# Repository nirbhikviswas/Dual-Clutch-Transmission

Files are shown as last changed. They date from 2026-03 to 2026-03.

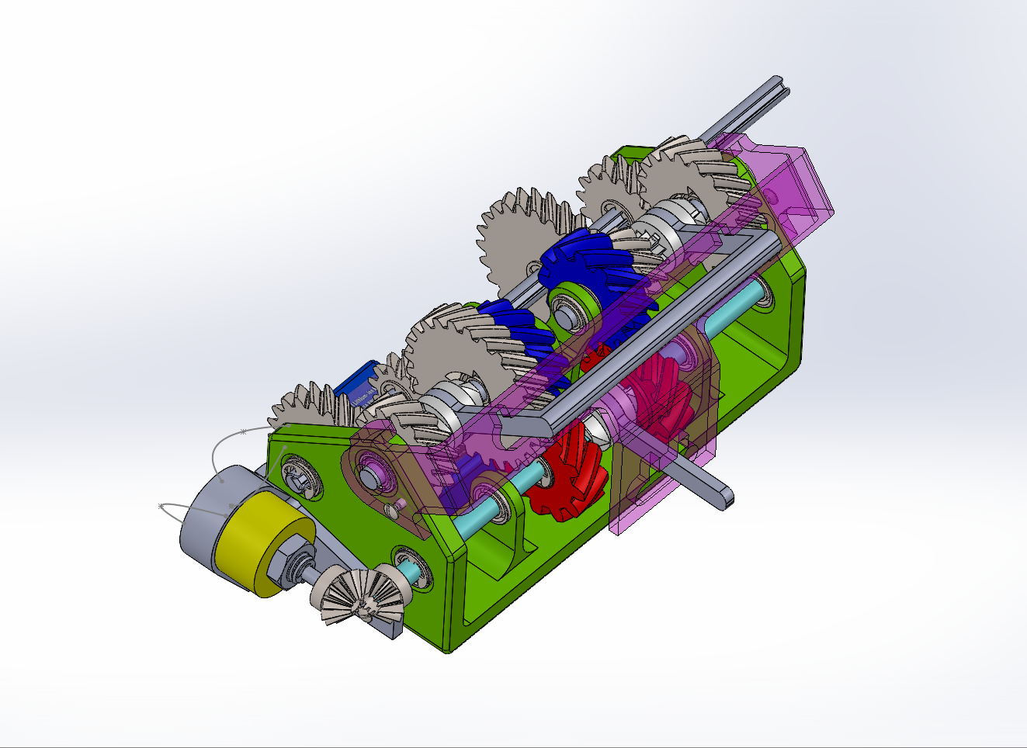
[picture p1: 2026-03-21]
Docs and Media/media/full assembly image 3.png

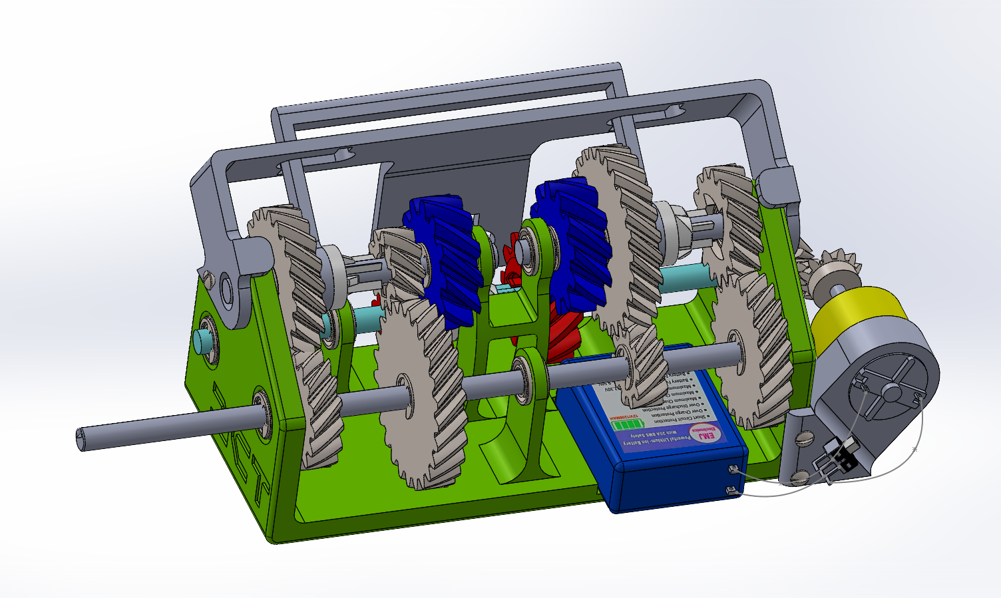
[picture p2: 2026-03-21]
Docs and Media/media/full assembly image 2.png

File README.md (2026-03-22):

# ⚙️ 4-Speed Modular Dual-Clutch Transmission (DCT)

 
> full assembly image 3
> 

## 📖 Description & Background
This repository contains the CAD files and assembly documentation for a **fully modular, 3D-printable 4-speed Dual-Clutch Transmission (DCT)**. It is powered by a 6V DC motor and designed to demonstrate high-efficiency kinetic energy transfer without the need for complex friction plates.

### 🚗 The Engineering: DCT vs. Manual Transmission
A traditional manual transmission interrupts power flow during a shift (the "neutral" gap). A Dual-Clutch Transmission solves this by splitting the gears across two independent shafts:
* **The Pros:** Near-seamless torque delivery, faster shift times, and higher mechanical efficiency since the "next" gear is pre-selected while the current one is driving.
* **The Cons:** Higher mechanical complexity, increased weight, and in real-world applications, complex thermal and fluid management. 

This model recreates that continuous power flow using a unique mechanical linkage, making the complex logic of a DCT visible and accessible.

---

## 🌟 Key Features & Innovations

### 1. The "Linked-Shift" Mechanical Logic
Real DCTs use electronic actuators (TCUs) to independently engage clutches. To make this model accessible and purely mechanical, we implemented a **slider-rod linkage system**. 
When you manually shift one set of gears, the connecting rod automatically pushes the slider on the opposite shaft into the "pre-selected" engagement position. This perfectly simulates the electronic hand-off of an actual DCT without needing a single line of code.

>

### 2. 100% Modular "Zero-Rigid-Fix" Design
The entire assembly follows a zero-rigid-fix philosophy:
* **No permanent adhesives:** Every gear, shaft, and bearing can be disassembled.
* **Tolerances:** Parts are engineered with optimized tolerances for 3D printing, ensuring a snug fit for bearings and minimized backlash between gear meshes. 

---

## 📐 Mechanical Architecture

### ⚙️ Gear Ratios Matrix
The transmission features four distinct speeds, alternating between the independent Odd and Even shafts:

| Gear | Ratio | Tooth Count (Drive:Driven) | Active Shaft |
| :--- | :--- | :--- | :--- |
| **1st** | 1:2.5 | 10T : 25T | Odd |
| **2nd** | 1:1.33 | 15T : 20T | Even |
| **3rd** | 1.33:1 | 20T : 15T | Odd |
| **4th** | 2.5:1 | 25T : 10T | Even |

### 🔩 Helical Gears vs. Spur Gears
To mimic high-performance automotive transmissions, this model utilizes **Helical Gears**.
* **Why Helical?** They offer smoother, progressive tooth engagement, operate much quieter than spur gears, and have a higher load-carrying capacity.
* **The Engineering Challenge:** Helical gears generate **axial thrust** (forces pushing the gear sideways along the shaft). 
* **Our Implementation:** We currently utilize circlips to lock the gears against this axial load as this small setup for demosntration of the mechanism has no load on the output shaft and the gears are small and 3D printed models. However, because circlips are not a solid, long-term solution for continuous thrust and loaded big useful models, upgrading to **shaft collars with thrust bearings** is recommended for higher loads.

### 🔺 Triangular Shaft Layout
Rather than a traditional straight-line sequential layout, this model uses a **Triangular Shaft Arrangement**. 
* **The Benefit:** It creates a much more compact gearbox. 
* **Load Distribution:** Torque is shared and distributed more evenly across the shafts. Bearings carry multi-directional loads, which reduces the bending moments on a single plane compared to a straight-line setup.

> 

---

## 📦 Bill of Materials (BOM)

All housing, gears, and shafts are fully 3D printable. The following hardware components are sourced from the market to complete the build:

| Item | Qty | Specification & Source Link | Use Case |
| :--- | :---: | :--- | :--- |
| **Miniature Ball Bearings** | 15 | [6800-ZZ (10x19x5mm)](https://omrook.com/6800-zz-id-10mm-od-19mm-h-5mm-miniature-ball-bearing/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) | Main shaft rotation |
| **DC Geared Motor** | 1 | [6V Arduino Geared Motor](https://www.amazon.in/INVENTO-1pcs-6V-Geared-Arduino/dp/B07R5FPR4D) *(or [Yellow Metal Variant](https://www.amazon.in/Geared-Motor-Original-Metal-Yellow/dp/B0B9KBJWW8))* | Main power drive |
| **E-Type Circlips** | 40 | [10mm Mild Steel (Black Coated)](https://onlyscrews.in/products/10mm-e-type-circlip-mild-steel-black-coated) | Internal gear locking |
| **External Circlips** | 10 | [10mm Shaft Diameter](https://omrook.com/external-circlip-for-10mm-shaft-diameter-100pcs/) | Shaft securing |
| **Thrust Bearings** | 10 | [AXK-1024 Needle Roller (10x24mm)](https://omrook.com/axk-1024-thrust-needle-roller-bearing-id-10mm-od-24mm/) | Axial load management |
| **Shaft Coupling** | 1 | [10mm x 6mm Aluminum Flexible](https://www.flyrobo.in/10mm-x-6mm-aluminum-flexible-shaft-coupling) | Motor-to-shaft connect |
| **Power Source** | 1 | [Lithium-ion Rechargeable Battery](https://www.amazon.in/Electronics-Lithium-ion-Rechargeable-Blutooth-Speakers/dp/B0G63YDBLR/) | Motor power |

*(Note: Standard M3/M4 machine screws are also required for mounting the motor and external housing).*

---

## 🛠️ Installation & Assembly Setup
1. **Print Tolerances:** Ensure your printer is well-calibrated. The gears require minimal stringing to prevent backlash.
2. **Post-Processing:** Sand the 3D-printed shafts lightly if the 6800-ZZ bearings do not slide on smoothly. **Do not force them**, as this breaks the zero-rigid-fix modularity.
3. **Linkage Alignment:** When installing the slider clutches, ensure the connecting rod is perfectly horizontal so shifting from 1st (Odd) smoothly engages 2nd (Even).

---

## 🚀 Roadmap & Future Upgrades
- [ ] **Thrust Upgrade:** Replace all load-bearing circlips with solid shaft collars to fully support the thrust bearings against the helical gear axial loads.
- [ ] **Electronic Actuation:** Design a mount for a servo motor to push the linkage rod, allowing for automated shifting via an Arduino.

## 🤝 Contributing
Suggestions and improvements are welcome! If you have ideas for better bearing mounts or modified gear ratios, please open an issue.

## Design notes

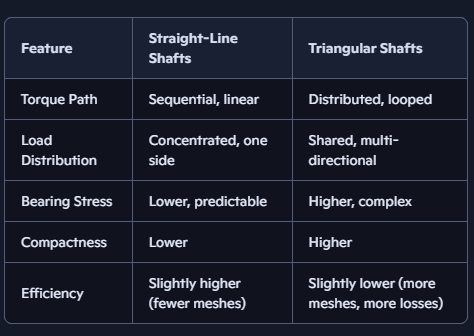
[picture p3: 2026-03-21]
Docs and Media/shaft arrangement pattern comparison 012347NV15February2026.png

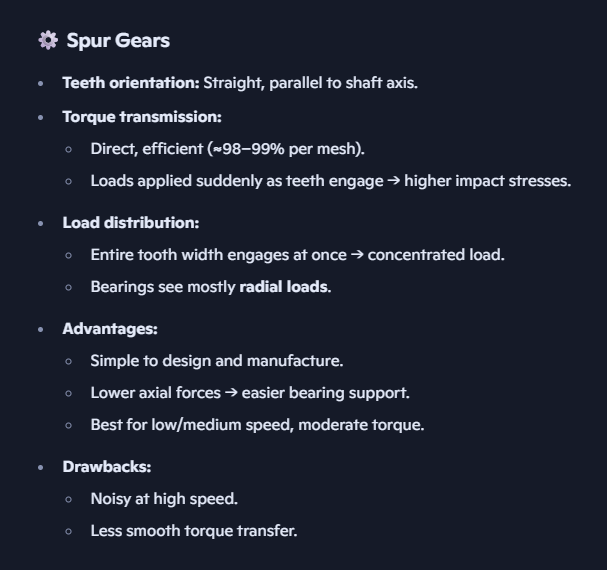
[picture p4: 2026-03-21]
Docs and Media/spur gears 012622NV15February2026.png

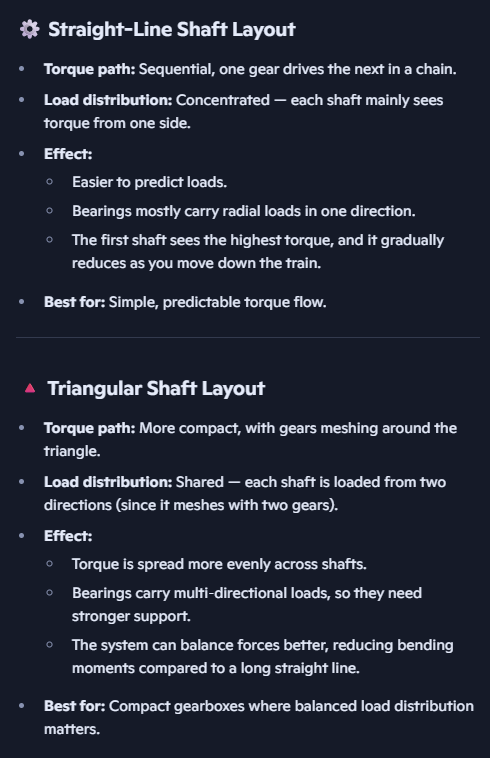
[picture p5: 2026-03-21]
Docs and Media/why triangular shaft arrangement 012313NV15February2026.png

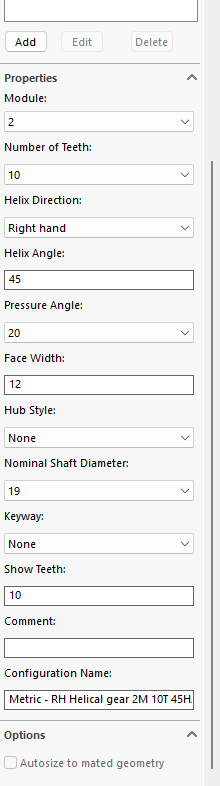
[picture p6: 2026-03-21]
Docs and Media/smallest gear 000956NV15February2026.png

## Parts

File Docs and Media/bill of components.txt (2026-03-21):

1. https://omrook.com/6800-zz-id-10mm-od-19mm-h-5mm-miniature-ball-bearing/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   X15

2. https://www.amazon.in/INVENTO-1pcs-6V-Geared-Arduino/dp/B07R5FPR4D
   OR https://www.amazon.in/Geared-Motor-Original-Metal-Yellow/dp/B0B9KBJWW8

3. https://onlyscrews.in/products/10mm-e-type-circlip-mild-steel-black-coated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 X40

4. https://omrook.com/external-circlip-for-10mm-shaft-diameter-100pcs/ X10

5. https://omrook.com/axk-1024-thrust-needle-roller-bearing-id-10mm-od-24mm/ X10

6. https://www.amazon.in/Electronics-Lithium-ion-Rechargeable-Blutooth-Speakers/dp/B0G63YDBLR/

7. https://www.flyrobo.in/10mm-x-6mm-aluminum-flexible-shaft-coupling

thrust bearings, screw, and some more things to be added

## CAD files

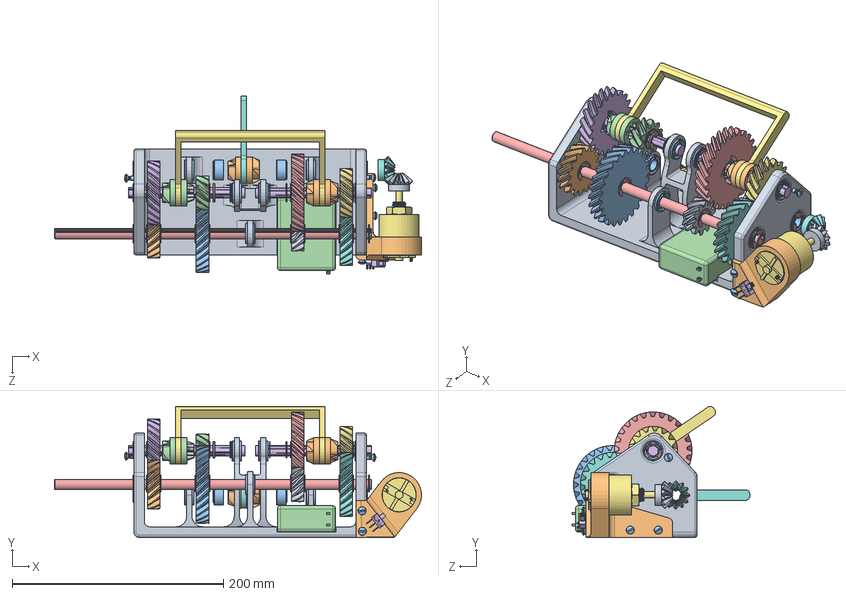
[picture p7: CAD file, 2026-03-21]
DCT CAD/FINAL ASSEMBLY.SLDASM
347.1 x 124.0 x 168.0 mm
Base
shifter gear1 x 2
radial ball bearing_68_am x 19
10T RH helical gear_indep
25T RH helical gear_3_am
20T RH helical gear_3_am
15T RH helical gear_3_am
20T LH helical gear_3_am
10T RH helical gear
15T LH helical gear_3_am
25T LH helical 44 deg not 45 gear_3_am
shifter gear2
output shaft
middle shaft with teeth x 2
motor_
straight bevel gear for shaft
straight bevel gear for motor1
motor hub ind
oval countersunk head tapping screw_am x 6
battery
e-ring external retaining ring_am x 25
slideswitch SS12D10_90_Degree
shifter handle
clutch shifter handle

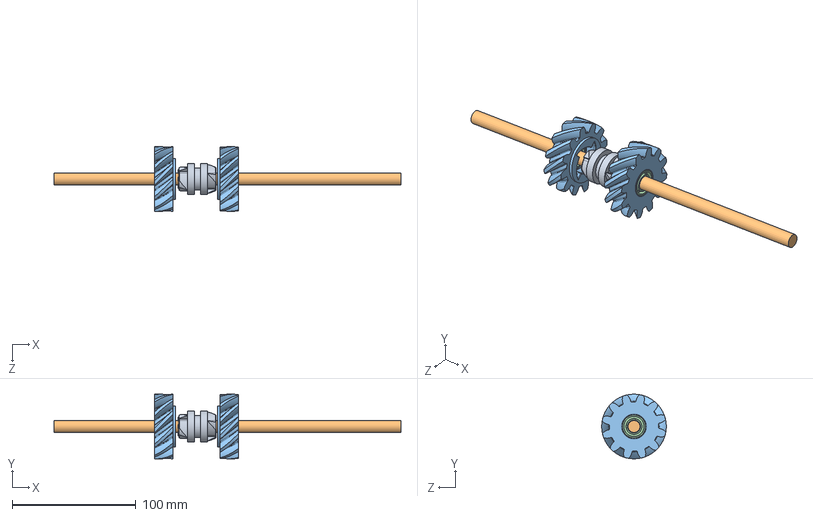
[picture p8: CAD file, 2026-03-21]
DCT CAD/reference assembly for creating feature.SLDASM
280.0 x 52.2 x 52.2 mm
input shaft
shifter gear1
helical gear_3_am 12 teeth x 2
radial ball bearing_68_am x 2

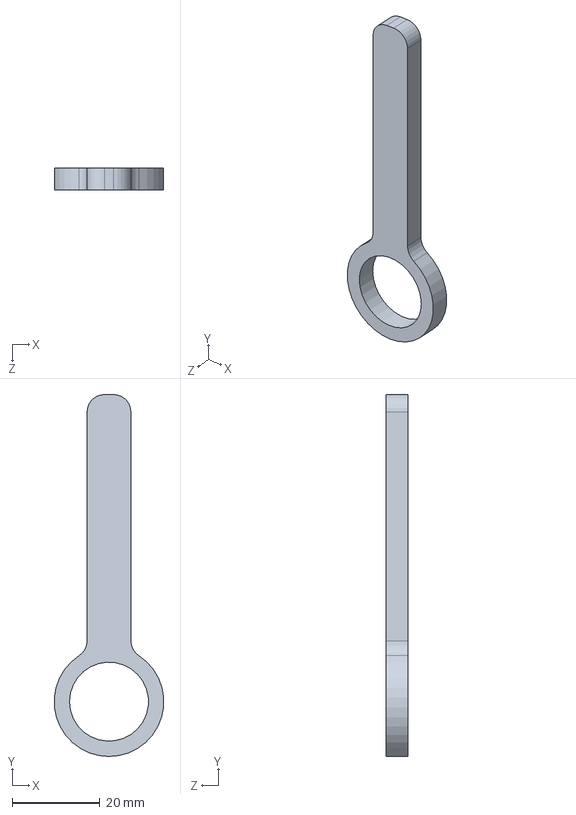
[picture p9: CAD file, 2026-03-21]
DCT CAD/clutch shifter handle.SLDPRT
24.9 x 82.5 x 5.00 mm

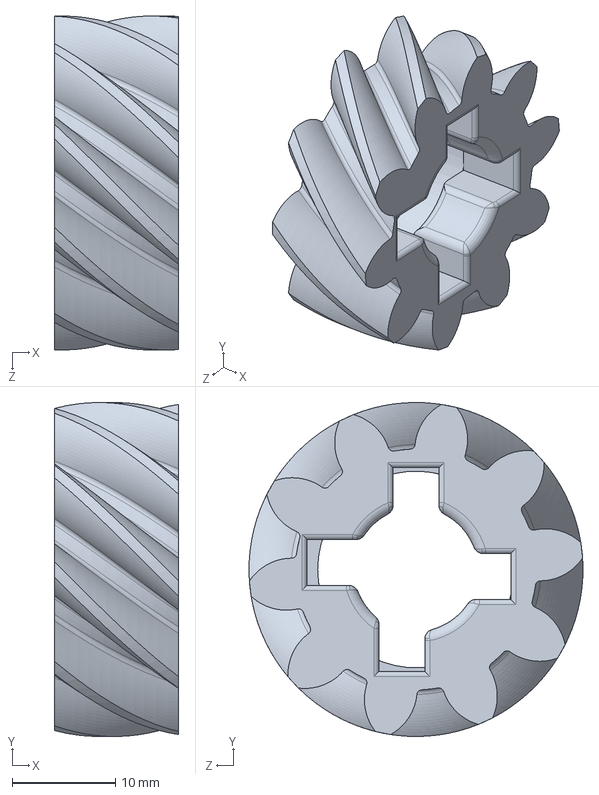
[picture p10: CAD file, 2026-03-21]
DCT CAD/10T RH helical gear_indep.SLDPRT
12.0 x 32.3 x 32.3 mm

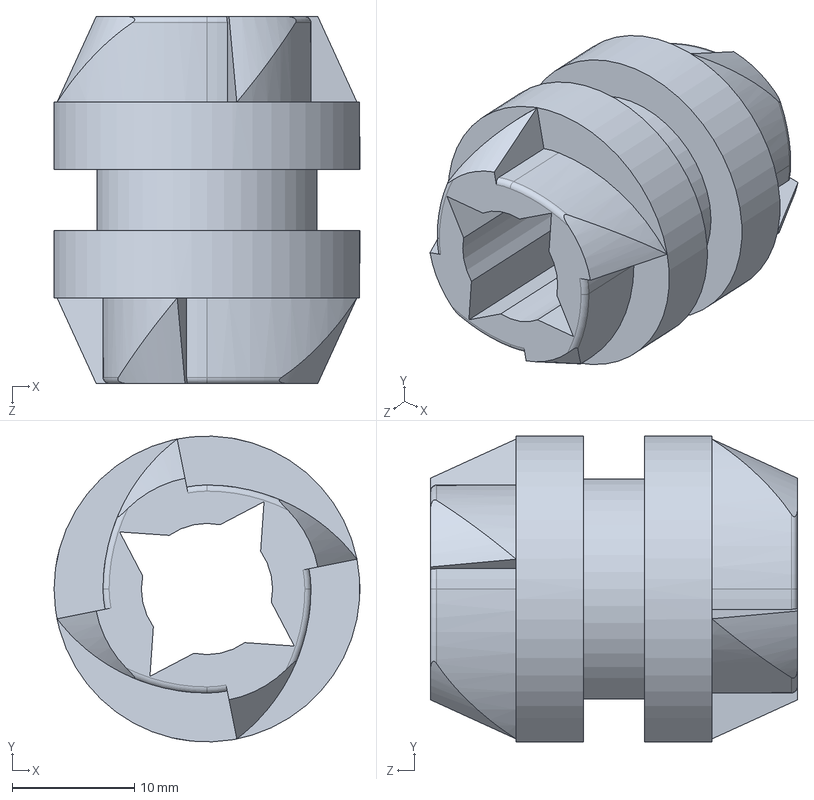
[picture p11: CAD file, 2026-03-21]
DCT CAD/shifter gear1.SLDPRT
25.0 x 25.0 x 30.0 mm

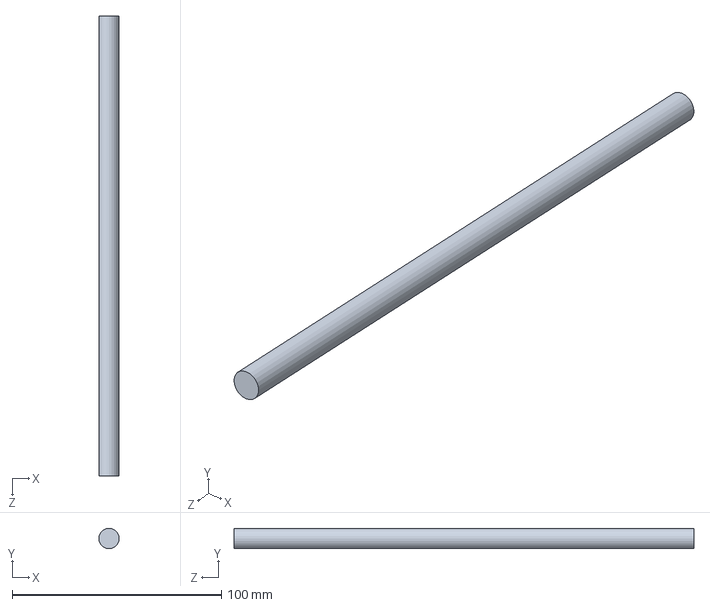
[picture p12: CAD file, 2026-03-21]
DCT CAD/middle shaft2.SLDPRT
9.72 x 9.72 x 220.0 mm

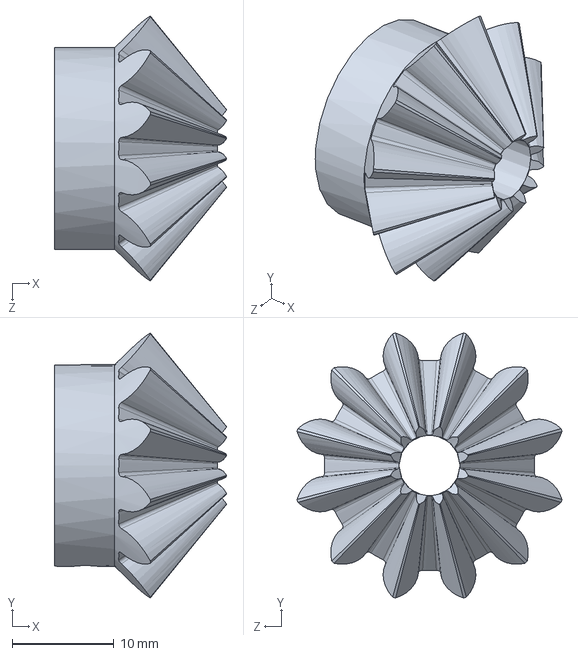
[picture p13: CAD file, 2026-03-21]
DCT CAD/straight bevel gear for motor.SLDPRT
16.9 x 26.0 x 26.0 mm

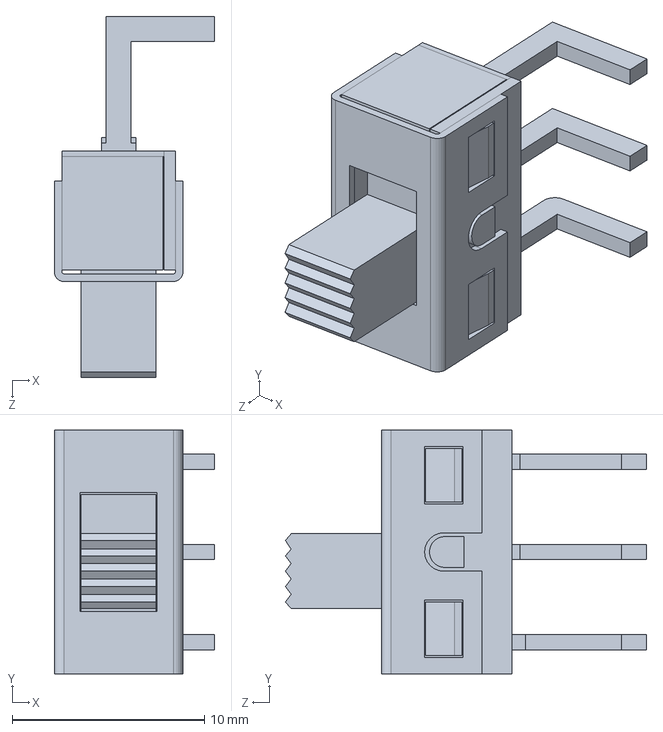
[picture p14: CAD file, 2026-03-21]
DCT CAD/slideswitch SS12D10_90_Degree.SLDPRT
8.35 x 12.7 x 18.8 mm

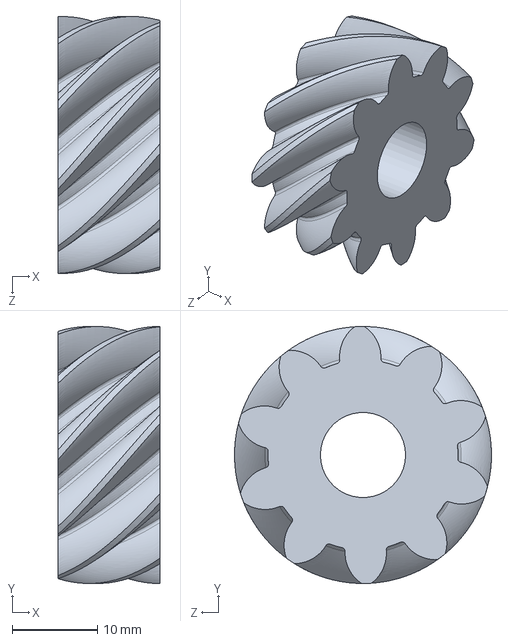
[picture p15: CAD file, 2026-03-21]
DCT CAD/10T LH helical 1.75 not 2 gear_3_am.SLDPRT
12.0 x 30.2 x 30.2 mm

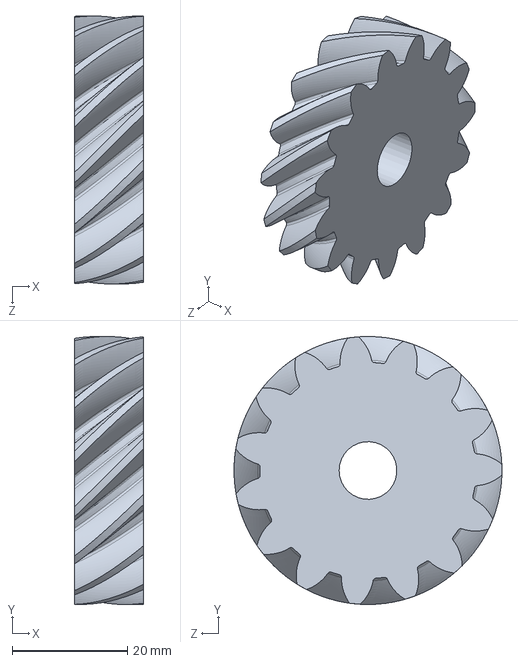
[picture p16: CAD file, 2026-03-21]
DCT CAD/25T LH helical 44 deg not 45 gear_3_am.SLDPRT
12.0 x 46.4 x 46.4 mm

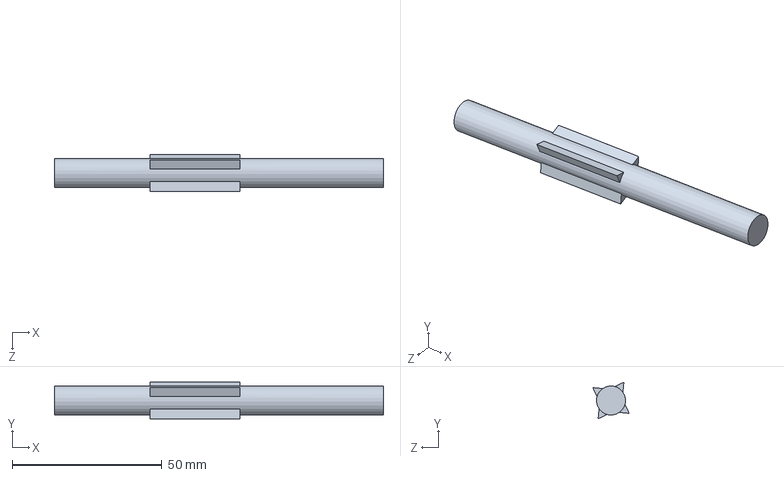
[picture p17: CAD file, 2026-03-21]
DCT CAD/middle shaft with teeth.SLDPRT
110.0 x 12.2 x 12.2 mm

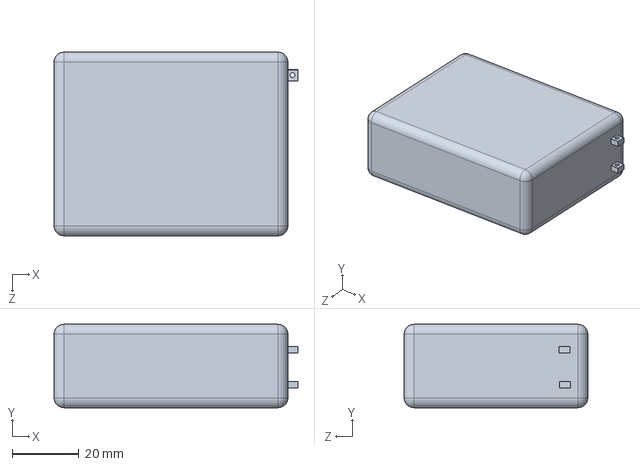
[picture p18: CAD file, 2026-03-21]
DCT CAD/battery.SLDPRT
73.0 x 25.0 x 55.0 mm

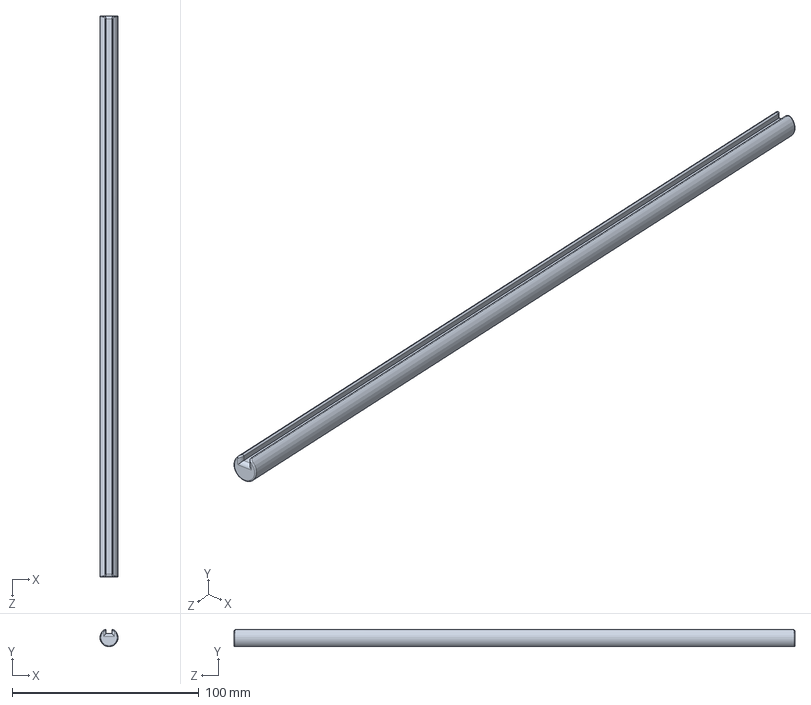
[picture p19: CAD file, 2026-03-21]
DCT CAD/output shaft.SLDPRT
9.71 x 9.20 x 300.0 mm

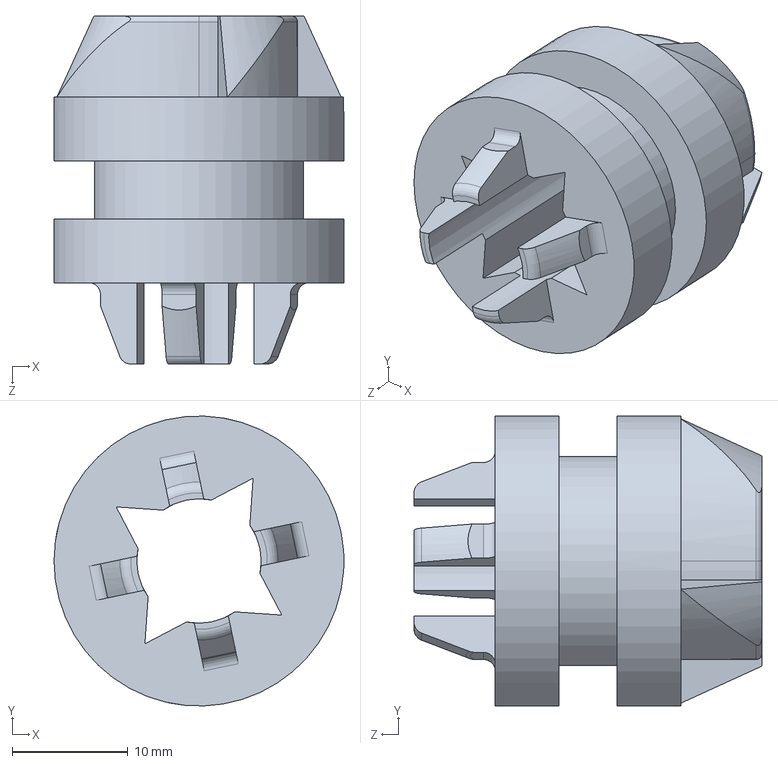
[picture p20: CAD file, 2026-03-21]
DCT CAD/shifter gear2.SLDPRT
25.0 x 25.0 x 30.0 mm

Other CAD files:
DCT CAD/20T LH helical gear_3_am.SLDPRT
DCT CAD/middle shaft1.SLDPRT
DCT CAD/15T RH helical gear_3_am.SLDPRT
DCT CAD/motor hub ind.SLDPRT
DCT CAD/10T RH helical gear.SLDPRT
DCT CAD/10T RH helical gear_3_am.SLDPRT
DCT CAD/12T input input-gears coupler helical gear_3_am.SLDPRT
DCT CAD/12T input input-gears coupler2 helical gear_3_am.SLDPRT
DCT CAD/15T LH helical gear_3_am.SLDPRT
DCT CAD/20T RH helical gear_3_am.SLDPRT
DCT CAD/25T LH helical gear_3_am.SLDPRT
DCT CAD/25T RH helical gear_3_am.SLDPRT
DCT CAD/Base.SLDPRT
DCT CAD/Flexible Coupling Coupler Helical Shaft .SLDPRT
DCT CAD/input shaft.SLDPRT
DCT CAD/middle shaft.SLDPRT
DCT CAD/motor hub.SLDPRT
DCT CAD/motor_.SLDPRT
DCT CAD/shifter gear.SLDPRT
DCT CAD/shifter handle.SLDPRT
DCT CAD/shifter hub.SLDPRT
DCT CAD/shifter slot for gear.SLDPRT
DCT CAD/shifter to shaft coupler teeth.SLDPRT
DCT CAD/straight bevel gear for motor1.SLDPRT
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

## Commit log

2026-03-21 Exact CAD as Uploaded in College Course
    This contains the exact CAD as submitted to the course instructor for evaluation plus some more files created during completion of the project. The ZIP is the actual files that I submitted tot he ins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
    [10T LH helical 1.75 not 2 gear_3_am.SLDPRT, 10T RH helical gear.SLDPRT, 10T RH helical gear_3_am.SLDPRT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]
2026-03-21 Folder rearrangement
    [10T LH helical 1.75 not 2 gear_3_am.SLDPRT, 10T RH helical gear.SLDPRT, 10T RH helical gear_3_am.SLDPRT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]
